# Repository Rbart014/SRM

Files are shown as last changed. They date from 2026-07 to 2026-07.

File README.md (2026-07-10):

# F-Class Solid Rocket Motor Static Characterization

**58.1 Ns | 25 mm OD | Single-Grain BATES | Designed in OpenMotor | Custom STM32 DAQ**

A fully documented amateur F-class solid rocket motor static fire test designed to build a complete engineering validation loop. This project includes 1D computational internal ballistics modeling, custom test stand fabrication, embedded C data acquisition development, and empirical thrust curve analysis for simulation calibration.

---

## Overview

| Parameter | Value |
|---|---|
| Motor Class | F (F78) |
| Total Impulse | 58.14 Ns (Actual) / 58.88 Ns (Predicted) |
| Peak Thrust | 93.07 N (Actual) / 134.67 N (Predicted) |
| Burn Time | ~1.40 s (Actual) / 0.72 s (Predicted) |
| Chamber Pressure | 8.24 MPa (Predicted) |
| Propellant Grain | Single-grain BATES (20.8 mm OD) |
| Propellant Length | 100 mm |
| Casing OD | 25 mm |
| Nozzle Throat Diameter | 3.89 mm |
| Nozzle Throat Length | 2.00 mm |
| Nozzle Exit Diameter | 8.20 mm |
| Expansion Ratio | 4.46 |
| DAQ Hardware | STM32 Microcontroller + HX711 |
| Test Stand Frame | 2040 Aluminum Extrusion |

---

## Repository Structure

```text
f-class-static-test/
├── simulation/           # OpenMotor 1D ballistics project files
├── DAQ/             # Custom C drivers for STM32 and HX711
├── test_data/            # Raw load cell CSVs from static firings
├── Cad/             # CAD files for custom metal motor mounts
├── images/               # Videos of firing, Post inspection
└── README.md

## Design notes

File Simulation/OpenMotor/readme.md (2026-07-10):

# OpenMotor 1D Internal Ballistics Simulation

This directory contains the computational simulation files used to predict the internal ballistics and thrust curve of the F-Class (F75) solid rocket motor prior to static testing. 

The primary tool used was **OpenMotor**, an open-source 1D internal ballistics solver for experimental solid rocket motors.

## Simulation Input Parameters

The initial predictive model was built using the following theoretical and geometric parameters:

| Component | Parameter | Value |
| :--- | :--- | :--- |
| **Propellant** | Type | KNSB (Potassium Nitrate / Sorbitol) |
| **Grain Geometry** | Configuration | Single-Grain BATES |
| | Outer Diameter (OD) | 0.819 in |
| | Length | 3.94 in |
| **Nozzle Geometry** | Throat Diameter | 0.153 in |
| | Throat Length | 0.079 in |
| | Exit Diameter | 0.323 in |
| | Expansion Ratio | 4.46 |
| | Convergence Half-Angle | 25° |
| | Divergence Half-Angle | 15° |
| **Assumptions** | C-Star Efficiency | 0.90 (Conservative sub-scale estimate) |

## Predicted vs. Empirical Calibration

The files currently in this directory represent the **pre-test predictive model**. 

Upon physical static testing, a significant deviation in the burn rate was observed. The OpenMotor simulation predicted a highly progressive burn over **0.72 seconds** with a peak chamber pressure of **1233 psi**. 

Empirical testing yielded a much longer, regressive burn over **~1.40 seconds**. Post-fire hardware inspection confirmed **0.000 in of nozzle throat erosion**, isolating the predictive failure entirely to the propellant characterization within the software.

## Files in this Directory
* `F78_Predictive_Model.eng` - The simulated thrust curve data exported from OpenMotor.
* `motor_sim.omtr` - The OpenMotor project save file.
* `SRM.png`

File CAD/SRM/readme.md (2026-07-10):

# Solid Rocket Motor (SRM) & Propellant Mold

> Mechanical design files, manufacturing tooling, and engineering drawings for an F-class Solid Rocket Motor.

## Overview
This directory contains the core 3D CAD assemblies and formal 2D drafts for the solid rocket motor. It encompasses the structural motor casing, the nozzle geometry, and the custom 3D-printed tooling required to cast the solid propellant grains.

## Core Models

### 1. SRM Hardware Assembly
The primary rocket motor structure, modeled around a **25 mm casing diameter**. The assembly details the integration of the motor casing, forward/aft closures, the converging-diverging nozzle, and the internal sacrificial thermal liners.

### 2. Propellant Casting Mold
Custom tooling designed for casting the solid propellant into a **single-grain Bates configuration**. The mold is desgined to be placed into the rocket casing as a type of experimental thermal liner made of polycarbonate.

### 3. Engineering Drawings
Formal 2D manufacturing drafts (`.pdf`). These drawings detail the critical dimensions, tolerances, and GD&T required to machine the motor hardware and verify the 3D-printed mold tolerances.

## Tools
* **Native CAD:** SolidWorks

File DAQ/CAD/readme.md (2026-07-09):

# Hardware Architecture: Static Test Stand

> Structural design and material specifications for the solid rocket motor static testing platform.

## Overview
The static test stand is engineered to safely secure the rocket motor during ignition and transfer the generated thrust linearly into the load cell for data acquisition. The physical structure balances modularity, rapid prototyping, and thermal resilience.

## Structural Components
* **Frame:** The core skeleton is constructed from **2040 aluminum extrusion**. This provides a rigid, modular backbone that resists bending moments during high-impulse static fires while allowing for easy adjustments to sensor placement.
* **Base & Mounts:** The primary base components and non-critical mounting brackets are 3D printed in **PETG**, chosen for its impact resistance and durability compared to standard PLA.
* **Motor Retention System:** The actual brackets holding the rocket motor are made of petg. They were able to withstand the heat as they never directly touched the rocket, only the screws that were holding the font closure and nozzle in place.

## Sensor Integration
The frame is specifically dimensioned to house the HX711 load cell assembly in direct axial alignment with the motor thrust vector, minimizing off-axis sheer forces and ensuring clean data transmission to the STM32 DAQ system.

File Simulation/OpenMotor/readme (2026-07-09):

# OpenMotor 1D Internal Ballistics Simulation

This directory contains the computational simulation files used to predict the internal ballistics and thrust curve of the F-Class (F75) solid rocket motor prior to static testing. 

The primary tool used was **OpenMotor**, an open-source 1D internal ballistics solver for experimental solid rocket motors.

## Simulation Input Parameters

The initial predictive model was built using the following theoretical and geometric parameters:

| Component | Parameter | Value |
| :--- | :--- | :--- |
| **Propellant** | Type | KNSB (Potassium Nitrate / Sorbitol) |
| **Grain Geometry** | Configuration | Single-Grain BATES |
| | Outer Diameter (OD) | 0.827 in |
| | Length | 3.94 in |
| **Nozzle Geometry** | Throat Diameter | 0.153 in |
| | Throat Length | 0.079 in |
| | Exit Diameter | 0.323 in |
| | Expansion Ratio | 4.46 |
| | Convergence Half-Angle | 25° |
| | Divergence Half-Angle | 15° |
| **Assumptions** | C-Star Efficiency | 0.90 (Conservative sub-scale estimate) |

## Predicted vs. Empirical Calibration

The files currently in this directory represent the **pre-test predictive model**. 

Upon physical static testing, a significant deviation in the burn rate was observed. The OpenMotor simulation predicted a highly progressive burn over **0.69 seconds** with a peak chamber pressure of **1195 psi**. 

Empirical testing yielded a much longer, regressive burn over **~1.40 seconds**. Post-fire hardware inspection confirmed **0.000 in of nozzle throat erosion**, isolating the predictive failure entirely to the propellant characterization within the software.

### Next Steps for Simulation (Iteration 2)
To build a calibrated model for future motor iterations, the empirical constants in OpenMotor's propellant database must be adjusted based on the static fire data:
1. **Burn Rate Coefficient (a) and Pressure Exponent (n):** The theoretical values utilized in this initial simulation significantly overestimated the burn rate for this specific chemical batch and curing environment. These parameters will be calibrated downward to match the 1.40 s empirical burn time.
2. **Efficiency Tuning:** Once burn time is calibrated via the burn rate constants, the C-Star efficiency parameter will be adjusted to accurately reflect the empirical 58.14 Ns total impulse.

## Files in this Directory
* `F75_Predictive_Model.eng` - The simulated thrust curve data exported from OpenMotor.
* `motor_sim.omtr` - The OpenMotor project save file.

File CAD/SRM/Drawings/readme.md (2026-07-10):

# Engineering & Manufacturing Drawings

> Formal 2D technical drafts and manufacturing specifications for the solid rocket motor and static test stand hardware.

## Overview
This directory contains the production-ready engineering drawings for all custom hardware. These documents establish the precise dimensions, tolerances, and material specifications required to transition the digital CAD models into physical, test-ready components.

### Motor Hardware
Detailed drafts for machining the primary pressure vessel and structural closures.
* **Motor Casing:** Specifications for the 25 mm outer diameter structural tube, including O-ring groove tolerances, wall thickness limits, and closure threading.
* **Closures & Nozzle:** Converging-diverging nozzle geometry and internal profiles designed to withstand peak chamber pressures and thermal flow.

## Standards & Formatting
All documents are provided in `.pdf` format for universal viewing by machinists or reviewers without requiring specialized CAD software. Drawings utilize standard Geometric Dimensioning and Tolerancing (GD&T) practices to clearly communicate functional limits and inspection criteria.

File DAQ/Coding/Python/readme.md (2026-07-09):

# Rocket Motor Thrust Logger GUI

> PC-side data acquisition and visualization software for an F-class solid rocket motor static test stand.

## Overview
This Python application serves as the ground station interface for the custom STM32 hardware. It establishes a serial connection to the microcontroller, reads incoming thrust telemetry, logs it securely to a timestamped CSV, and automatically generates a thrust curve plot for immediate performance analysis post-burn.

## Features
* **Live Telemetry:** Real-time thrust display built with Tkinter, utilizing a dedicated background thread to prevent UI blocking during high-speed serial reads.
* **Automated Data Logging:** Captures live UART data streams (115200 baud) and safely writes to uniquely timestamped CSV files, preventing data loss between static test fires.
* **Auto-Graphing:** Automatically parses the saved CSV and generates a scaled Thrust Curve (Time vs. Newtons) using Matplotlib immediately upon test completion.

## Technical Stack
* **Language:** Python 3
* **Libraries:** `tkinter` (GUI), `pyserial` (Hardware Comm), `matplotlib` (Data Visualization), `threading`, `csv`
* **Hardware Integration:** Designed to interface directly with STM32 UART outputs processing HX711 load cell data.

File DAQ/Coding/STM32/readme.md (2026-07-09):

# Rocket Motor DAQ Firmware

> Custom STM32 firmware for data acquisition on an F-class solid rocket motor static test stand.

## Overview
This project interfaces an STM32 microcontroller with an HX711 load cell amplifier to capture high-fidelity thrust data during static fires. It converts raw 24-bit ADC counts into real-time thrust measurements (Newtons) for performance analysis.

## Features
* **Precision DAQ:** Custom bit-banging C driver for the HX711 24-bit ADC.
* **Live Calibration:** Implements automated taring and applies a calibrated scale factor (`10435.78`).
* **Serial Streaming:** Transmits formatted floating-point data over UART (115200 baud) for live PC logging.

## Hardware Stack
* STM32 Microcontroller
* HX711 Load Cell Amplifier
* 2040 Aluminum Extrusion Frame
* Custom Metal Motor Retainers

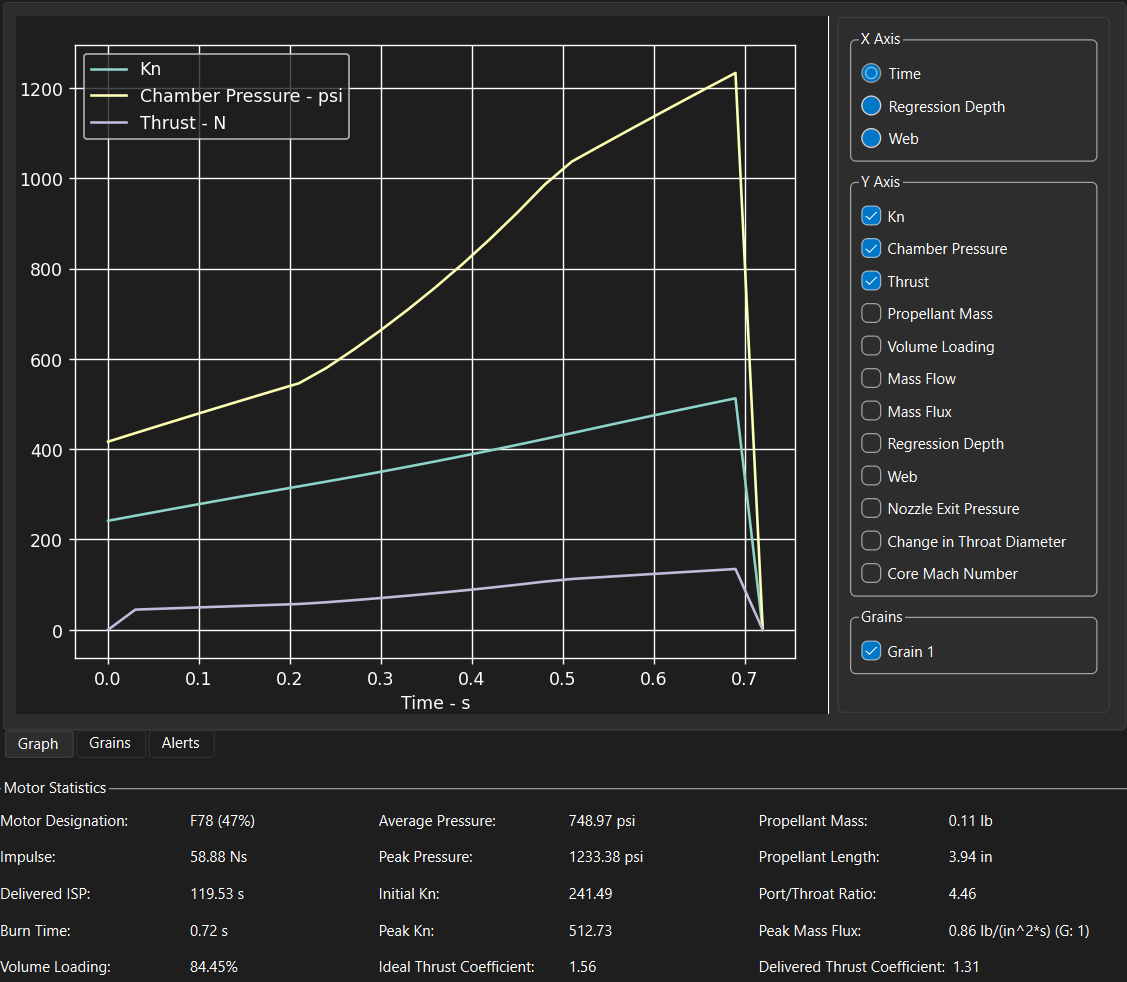
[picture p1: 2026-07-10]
Simulation/OpenMotor/SRM.png

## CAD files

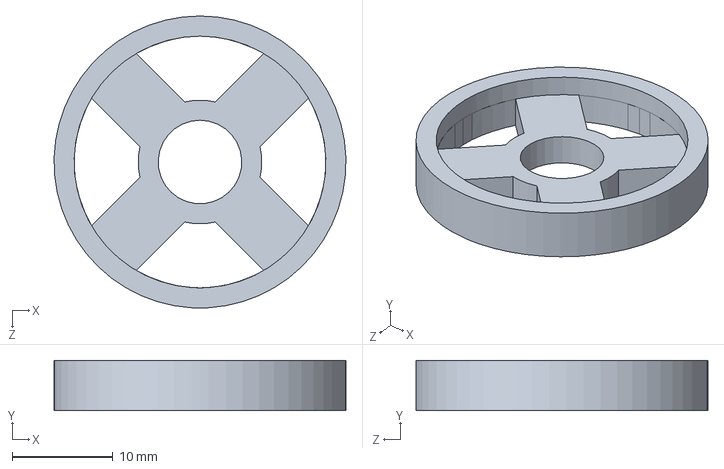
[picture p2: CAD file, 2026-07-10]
CAD/SRM/F-Class_Mold_Cap.SLDPRT
29.0 x 5.00 x 29.0 mm

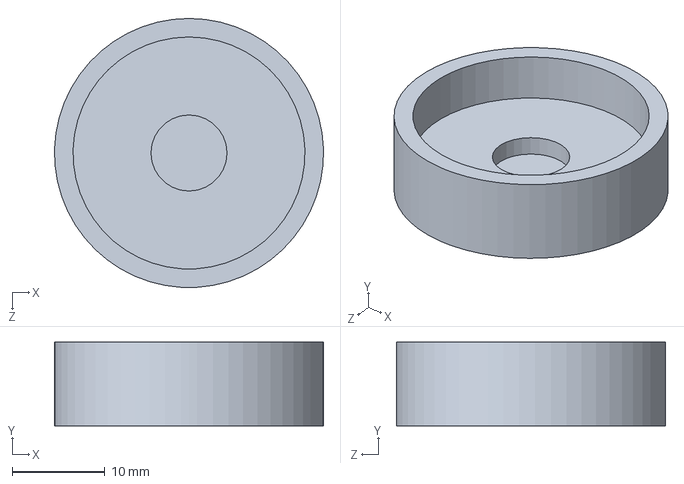
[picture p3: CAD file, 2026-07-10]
CAD/SRM/Mold_Bottom_Cap.SLDPRT
29.0 x 9.00 x 29.0 mm

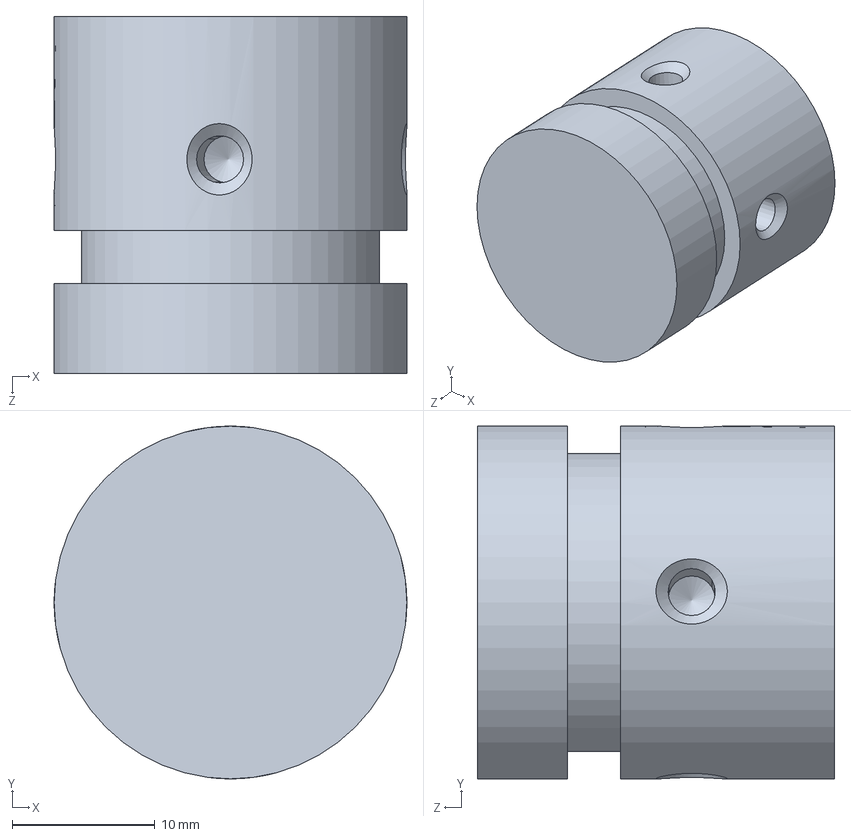
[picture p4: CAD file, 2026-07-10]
CAD/SRM/F-Class_Bulkhead.SLDPRT
24.7 x 24.7 x 25.0 mm

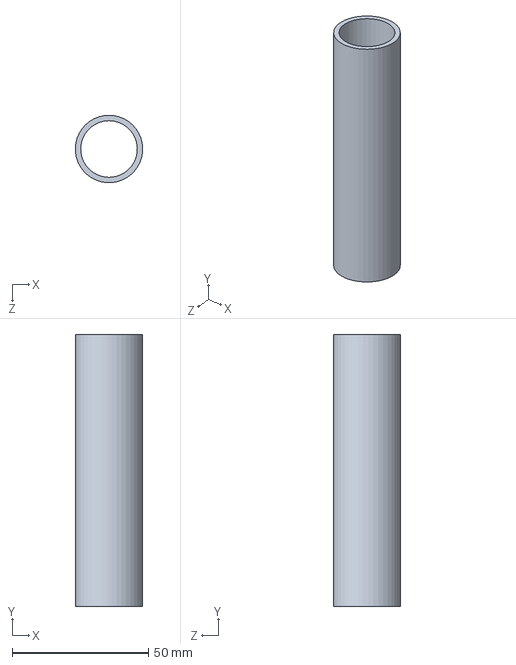
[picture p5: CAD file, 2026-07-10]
CAD/SRM/Thermal_Liner_Mold.SLDPRT
24.8 x 100.0 x 24.8 mm

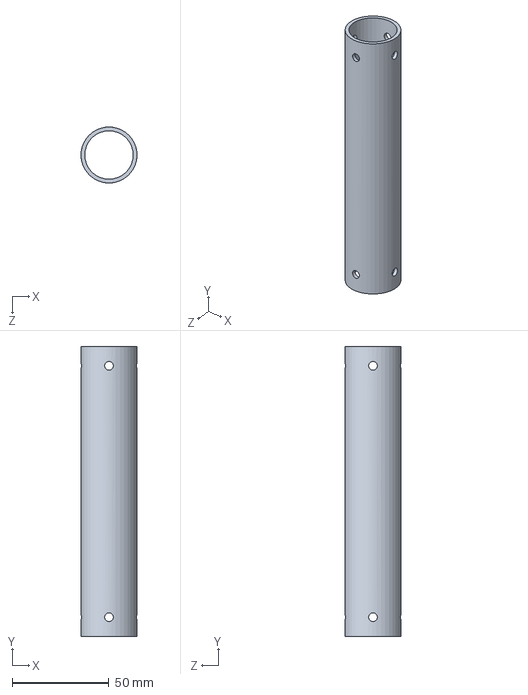
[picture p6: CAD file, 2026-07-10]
CAD/SRM/F-Class_Casing.SLDPRT
29.0 x 150.0 x 29.0 mm

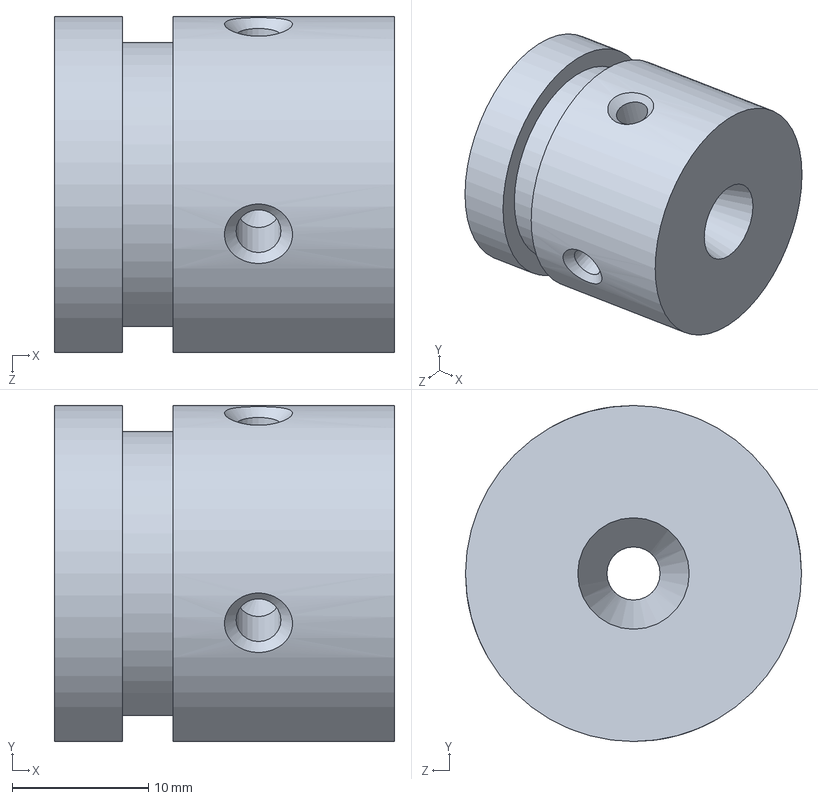
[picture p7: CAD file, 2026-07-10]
CAD/SRM/F-Class_Nozzle.SLDPRT
25.0 x 24.7 x 24.7 mm

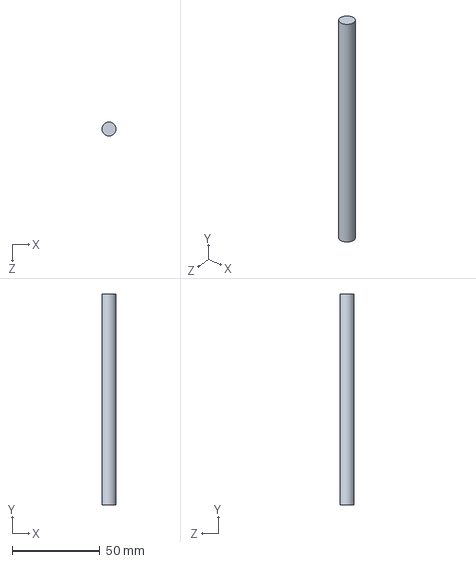
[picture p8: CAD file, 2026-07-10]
CAD/SRM/8MM_Mandrel.SLDPRT
7.99 x 120.0 x 8.00 mm

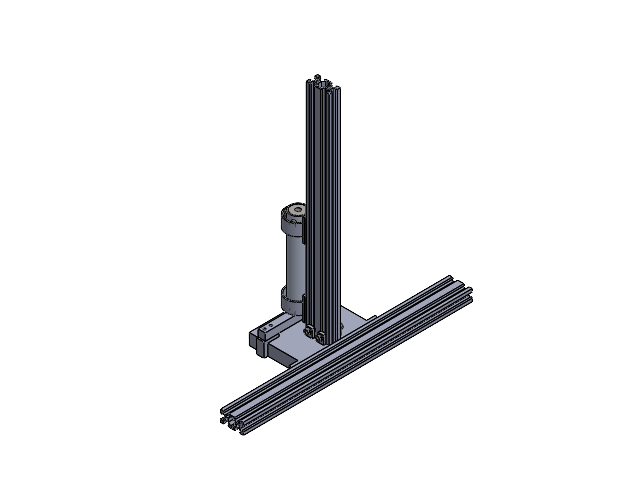
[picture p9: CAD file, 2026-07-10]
DAQ/CAD/Test_Stand.SLDASM
2040 400mm x 2
Test_Stand_Base_Plate
F-Class_Nozzle
F-Class_Bulkhead
F-Class_Casing
Thermal_Liner
91290A221_Black-Oxide Alloy Steel Socket Head Screw x 9
F-Class_Collar x 2
Load_Cell
91290A113_Black-Oxide Alloy Steel Socket Head Screw x 5
91290A224_Black-Oxide Alloy Steel Socket Head Screw x 4

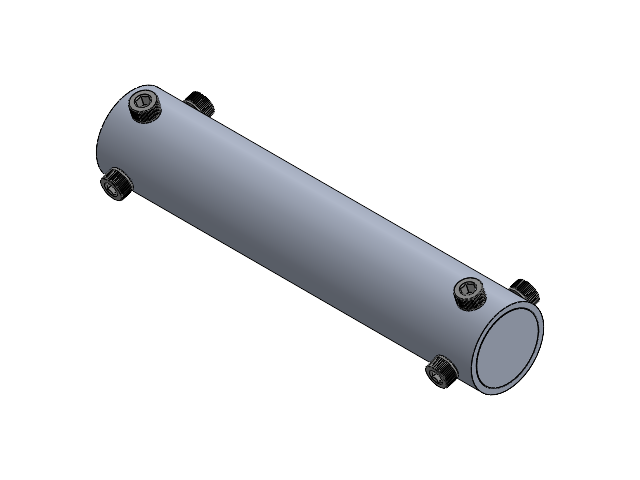
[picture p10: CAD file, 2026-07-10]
CAD/SRM/F-Class_Assembly.SLDASM
F-Class_Nozzle
F-Class_Bulkhead
F-Class_Casing
Thermal_Liner
91290A221_Black-Oxide Alloy Steel Socket Head Screw x 8

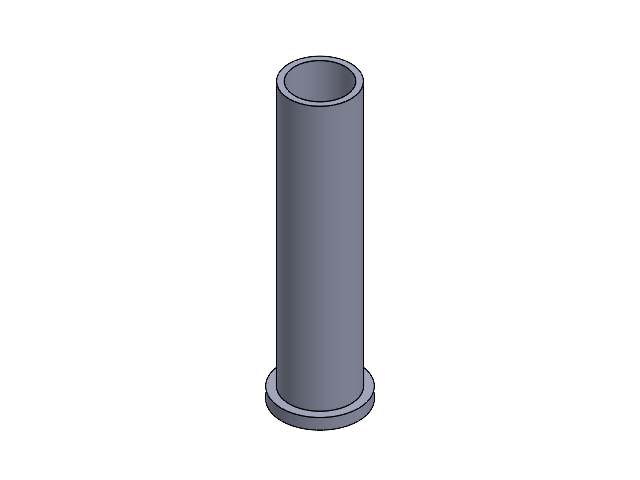
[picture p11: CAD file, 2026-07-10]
CAD/SRM/F-Class_Casting_Mold_Assembly.SLDASM
F-Class_Mold_Bottom
F-Class_Mold_Case

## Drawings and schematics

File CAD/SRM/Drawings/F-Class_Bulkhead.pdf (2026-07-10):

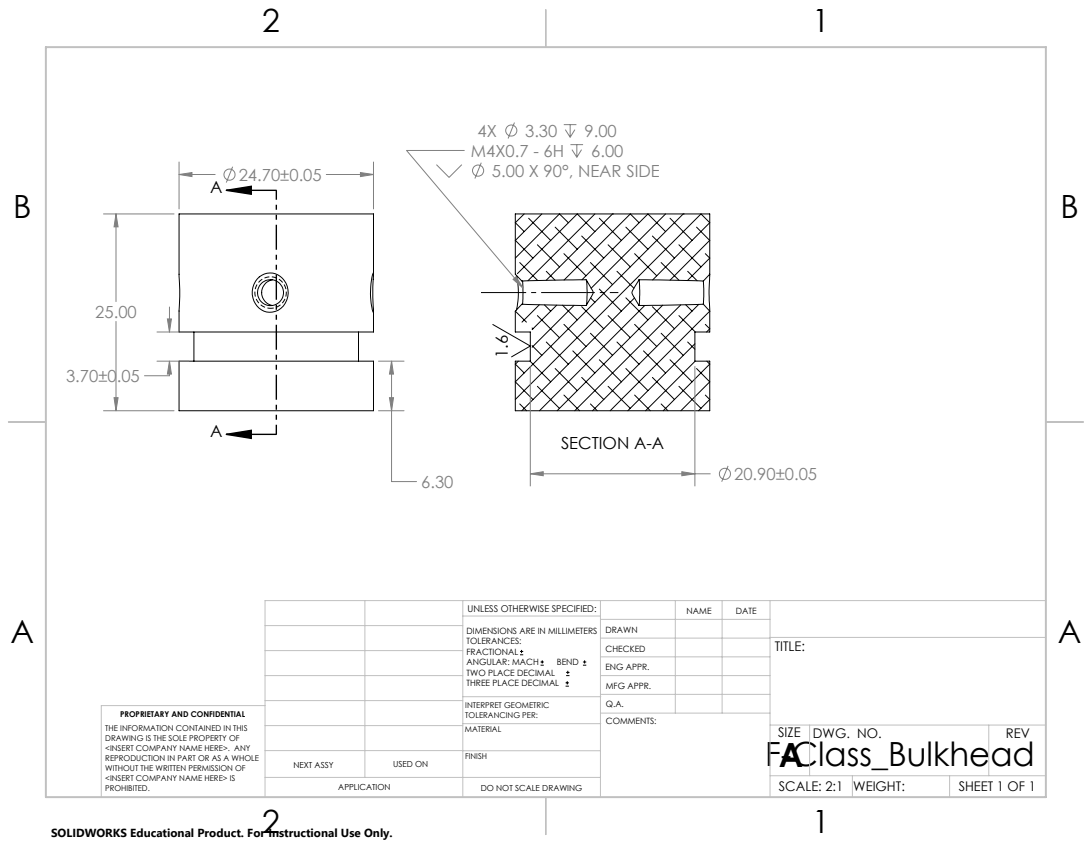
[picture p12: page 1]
M4X0.7 - 6H 6.00 5.00 X 90°, NEAR SIDE; SECTION A-A

UNLESS OTHERWISE SPECIFIED: | | NAME | DATE
DIMENSIONS ARE IN MILLIMETERS TOLERANCES: FRACTIONAL ANGULAR: MACH BEND TWO PLACE DECIMAL THREE PLACE DECIMAL | DRAWN

CHECKED | | | TITLE:

ENG APPR.
MFG APPR.

INTERPRET GEOMETRIC TOLERANCING PER: | Q.A.
MATERIAL | F-Class_Bulkhead | SIZE A | DWG. NO. | REV

PROPRIETARY AND CONFIDENTIAL
THE INFORMATION CONTAINED IN THIS
DRAWING IS THE SOLE PROPERTY OF
<INSERT COMPANY NAME HERE>. ANY
REPRODUCTION IN PART OR AS A WHOLE
WITHOUT THE WRITTEN PERMISSION OF
<INSERT COMPANY NAME HERE> IS
PROHIBITED.

NEXT ASSY | USED ON | FINISH

APPLICATION | DO NOT SCALE DRAWING | | SCALE: 2:1 | WEIGHT: | SHEET 1 OF 1

SOLIDWORKS Educational Product. For Instructional Use Only.

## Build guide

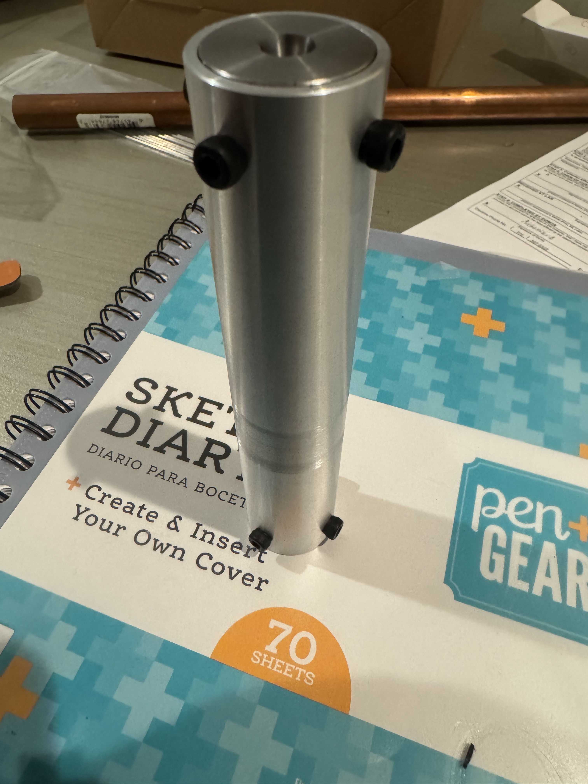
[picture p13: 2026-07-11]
Video and Images/Test 1/Full Assembly.jpg

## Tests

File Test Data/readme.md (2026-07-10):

## Static Fire Results
Below are the empirical thrust curves generated by the Python ground station during recent static test fires. The data tracking did start a few seconds before actual ignitiion. 

**Test Iteration 1:**
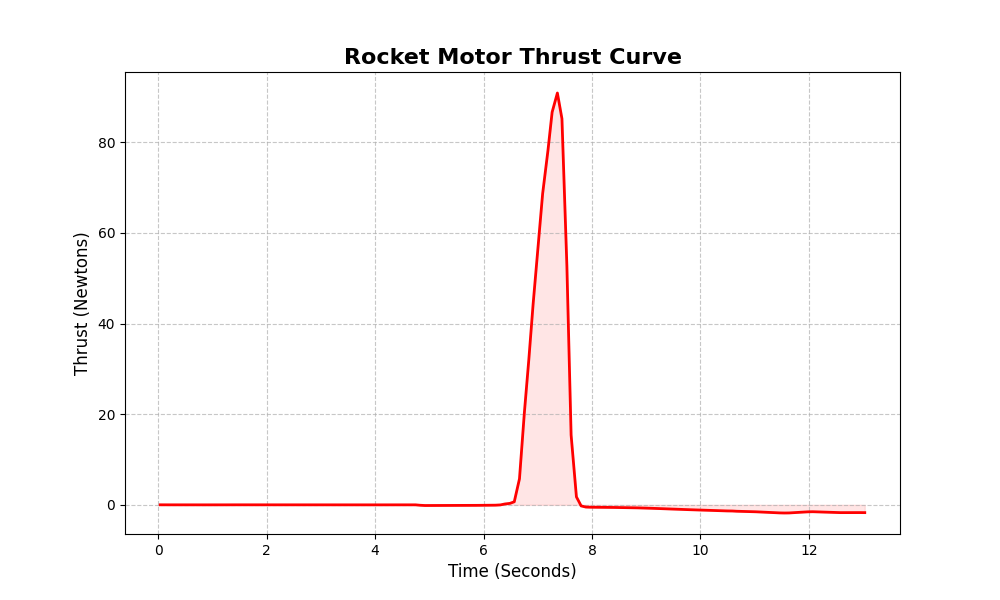
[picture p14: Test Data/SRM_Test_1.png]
Thrust Curve Test 1


**Test Iteration 2:**
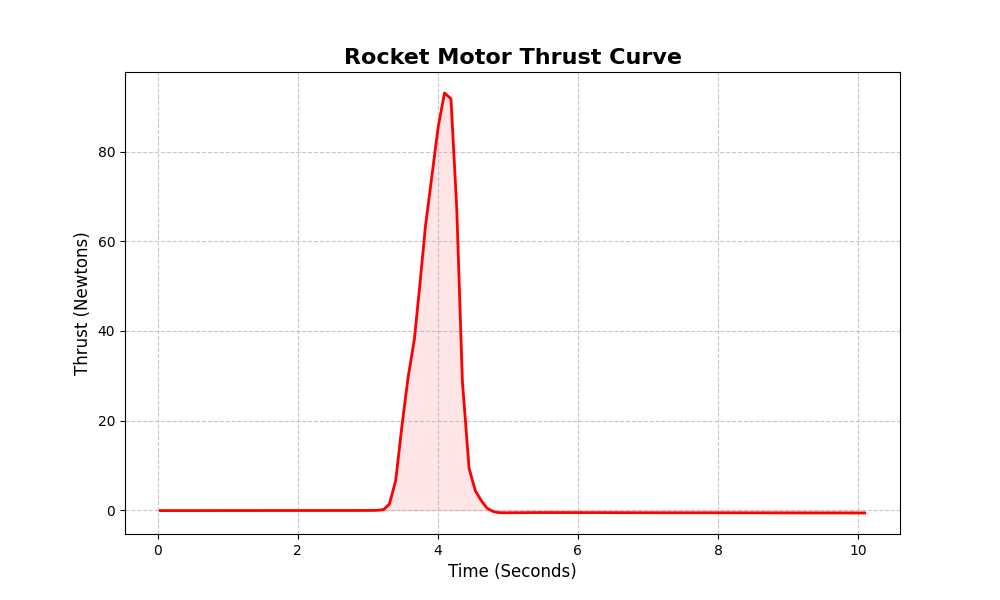
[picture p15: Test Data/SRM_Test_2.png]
Thrust Curve Test 2


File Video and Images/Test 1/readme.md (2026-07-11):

# Static Fire Test 01

This directory contains the documentation, media, and post-test breakdown for the first static fire test of the custom solid rocket motor.

## Motor Specifications
* **Propellant:** KNSB (Meltcast)
* **Configuration:** Single-grain Bates (20.8 mm OD)
* **Casing:** 25 mm diameter
* **Thermal Management:** 3D Printed Polycarbonate (PC) liner

## Test 01 Media & Documentation
The following files document the pre-test assembly and post-test structural and thermal evaluation:

* **Pre-Test Files:** 
  * `Full Assembly.jpg`
  * `KNSB meltcast.jpg` 
  * `Igniter.jpg`
  * `PC mold_liner.jpg`
* **Post-Test Breakdown:** 
  * `Assembly after test.jpg`
  * `Casing after test.jpg`
  * `Front Closure and Nozzle after test.jpg`

## Static Fire Footage
* `Test 1 video.mp4`

## Test Objectives
The primary goal of Test 01 was to establish a baseline for the motor's internal ballistics and to validate the survivability of the 3D-printed PC thermal liner under live pressure and thermal soak-back conditions.

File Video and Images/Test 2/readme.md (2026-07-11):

# Static Fire Test 02

This directory contains the post-test documentation and media for the second static fire test of the custom solid rocket motor. 

## Motor Specifications
* **Propellant:** KNSB (Meltcast)
* **Configuration:** Single-grain Bates (20.8 mm OD)
* **Casing:** 25 mm diameter
* **Thermal Management:** 3D Printed Polycarbonate (PC) liner

## Test 02 Media & Documentation
This iteration specifically focuses on post-test component degradation. The following files document the structural and thermal evaluation after firing:

* **Post-Test Breakdown:** 
  * `Casing post fire.jpg`
  * `Nozzle and Front Closure post fire.jpg`
  * `Nozzle post fire.jpg`
  * `PC liner post fire.jpg`

* **Static Fire Footage:** 
  * `Test 2 video.mp4` (Includes the complete video recording of the live static fire on the test stand).

## Test Objectives & Observations
Building upon the baseline established in Test 01, this firing continued to evaluate internal ballistics and the structural safety of the motor components. The post-fire media specifically highlights the survivability of the 3D-printed PC thermal liner and assesses thermal soak-back wear on the aluminum casing, closures, and nozzle.

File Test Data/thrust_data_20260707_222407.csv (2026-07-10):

Time (s) | Thrust (N)
0.036 | -0.060
0.041 | -0.061
0.044 | -0.060
0.047 | -0.062
0.047 | -0.062
0.047 | -0.065
0.047 | -0.063
0.052 | -0.062
0.052 | -0.063
0.052 | -0.063
0.052 | -0.061
0.052 | -0.063
0.085 | -0.062
0.181 | -0.061
0.266 | -0.063
0.357 | -0.064
0.439 | -0.066
0.532 | -0.061
0.615 | -0.066
0.707 | -0.065
0.784 | -0.058
0.879 | -0.060
0.961 | -0.062
1.055 | -0.061
1.135 | -0.057
1.229 | -0.062
1.315 | -0.063
1.387 | -0.063
1.483 | -0.064
1.563 | -0.064
1.659 | -0.064
1.738 | -0.067
1.835 | -0.062
1.924 | -0.055
2.008 | -0.064
2.091 | -0.062
2.184 | -0.057
2.265 | -0.055
2.359 | -0.055
2.439 | -0.055
2.533 | -0.053
2.620 | -0.052
2.693 | -0.053
2.788 | -0.047
2.870 | -0.041
2.966 | -0.039
3.055 | -0.031
3.135 | -0.001
3.225 | 0.160
3.309 | 1.422
3.398 | 6.618
3.486 | 18.656
3.573 | 29.390
3.665 | 38.188
3.744 | 50.448
3.824 | 63.506
3.919 | 75.093
4.006 | 85.638
4.095 | 93.074
4.187 | 91.798
4.270 | 67.390
4.350 | 28.886
4.446 | 9.338
4.535 | 4.360
4.620 | 2.169
4.700 | 0.507
4.795 | -0.308
4.868 | -0.518
4.963 | -0.555
5.055 | -0.542
5.134 | -0.523
5.229 | -0.517
5.308 | -0.513
5.403 | -0.508
5.489 | -0.516
5.570 | -0.511
5.651 | -0.508
5.750 | -0.507
5.840 | -0.510
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

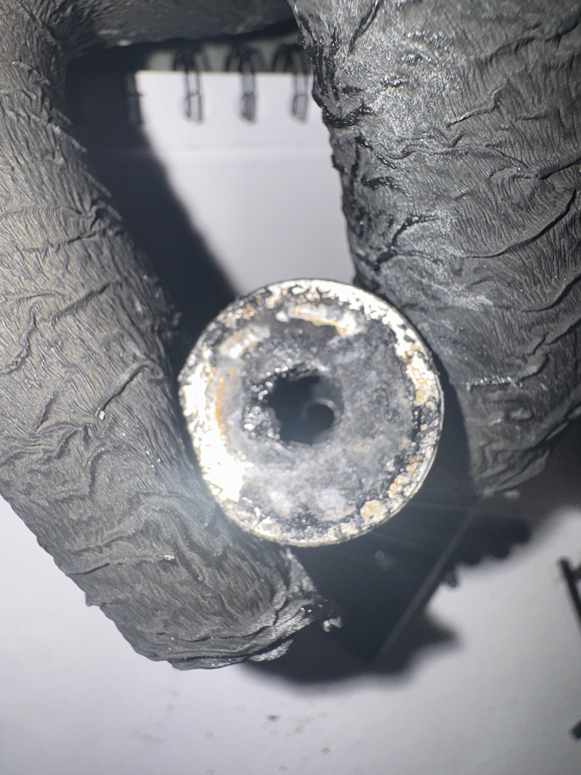
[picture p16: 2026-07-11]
Video and Images/Test 2/Nozzle post fire.jpg

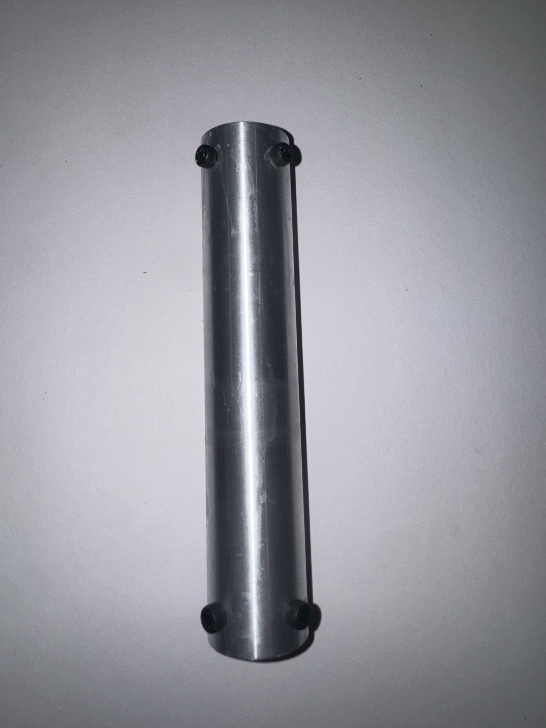
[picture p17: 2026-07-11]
Video and Images/Test 1/Assembly after test.jpg

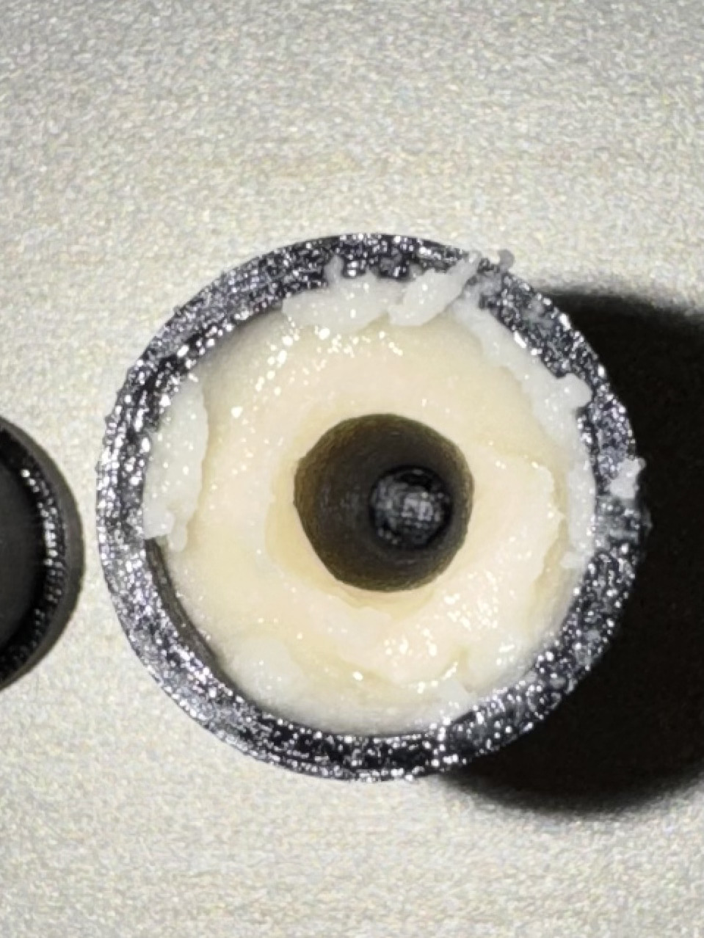
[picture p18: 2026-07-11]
Video and Images/Test 1/KNSB meltcast.jpg

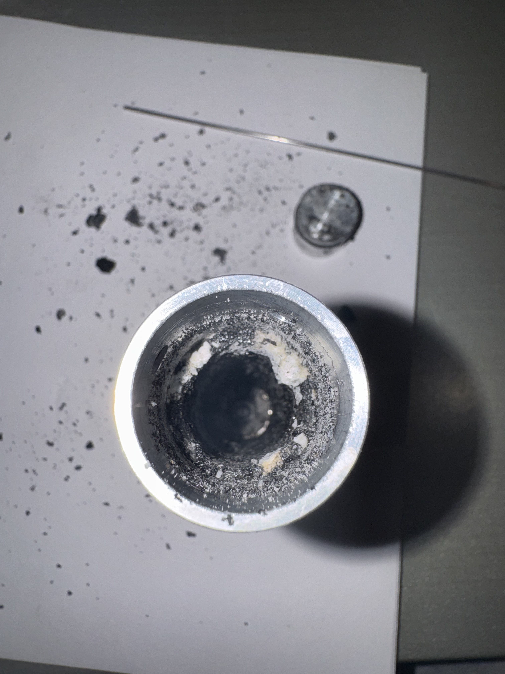
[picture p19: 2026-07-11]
Video and Images/Test 1/Casing after test.jpg

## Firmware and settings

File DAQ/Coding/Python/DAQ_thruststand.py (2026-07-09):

import tkinter as tk
from tkinter import messagebox
import serial
import time
import csv
import threading
import matplotlib.pyplot as plt

class ThrustLoggerGUI:
    def __init__(self, root):
        self.root = root
        self.root.title("🚀 Rocket Thrust Logger")
        self.root.geometry("400x350")
        self.root.configure(bg="#f0f0f0")
        
        self.is_recording = False
        self.serial_port = None
        self.data_thread = None
        self.start_time = 0
        self.csv_file = None
        self.csv_writer = None
        
        # --- NEW: Variable to hold our unique filename for each run ---
        self.current_filename = "" 
        
        # --- UI Elements ---
        tk.Label(root, text="COM Port:", font=("Arial", 12), bg="#f0f0f0").pack(pady=(20, 5))
        
        self.port_entry = tk.Entry(root, font=("Arial", 12), justify="center")
        self.port_entry.insert(0, "COM7") # Updated default to your working COM7!
        self.port_entry.pack(pady=5)
        
        self.thrust_label = tk.Label(root, text="0.000 N", font=("Courier", 40, "bold"), fg="#0052cc", bg="#f0f0f0")
        self.thrust_label.pack(pady=20)
        
        self.status_label = tk.Label(root, text="Status: Ready", font=("Arial", 10, "italic"), fg="gray", bg="#f0f0f0")
        self.status_label.pack(pady=5)
        
        # --- Buttons ---
        self.start_btn = tk.Button(root, text="🟢 Start Recording", font=("Arial", 14, "bold"), bg="#a8e6cf", command=self.start_recording)
        self.start_btn.pack(pady=5, fill="x", padx=60)
        
        self.stop_btn = tk.Button(root, text="🛑 Stop, Save & Graph", font=("Arial", 14, "bold"), bg="#ff8b94", state=tk.DISABLED, command=self.stop_recording)
        self.stop_btn.pack(pady=5, fill="x", padx=60)
        
    def start_recording(self):
        port = self.port_entry.get()
        
        try:
            self.serial_port = serial.Serial(port, 115200, timeout=1)
            time.sleep(1) 
        except Exception as e:
            messagebox.showerror("Connection Error", f"Could not open {port}.\n\nError: {e}")
            return
            
        # --- NEW: Create a unique file based on the exact date and time ---
        timestamp = time.strftime("%Y%m%d_%H%M%S")
        self.current_filename = f"thrust_data_{timestamp}.csv"
        
        self.csv_file = open(self.current_filename, "w", newline="")
        self.csv_writer = csv.writer(self.csv_file)
        self.csv_writer.writerow(["Time (s)", "Thrust (N)"])
        
        self.is_recording = True
        self.start_time = time.time()
        
        self.start_btn.config(state=tk.DISABLED)
        self.stop_btn.config(state=tk.NORMAL)
        self.port_entry.config(state=tk.DISABLED)
        self.status_label.config(text="Status: 🔴 RECORDING...", fg="red")
        
        self.data_thread = threading.Thread(target=self.read_serial_data, daemon=True)
        self.data_thread.start()
        
    def read_serial_data(self):
        while self.is_recording and self.serial_port.is_open:
            try:
                if self.serial_port.in_waiting > 0:
                    line = self.serial_port.readline().decode('utf-8', errors='ignore').strip()
                    if line:
                        try:
                            thrust = float(line)
                            current_time = time.time() - self.start_time
                            
                            self.csv_writer.writerow([f"{current_time:.3f}", f"{thrust:.3f}"])
                            self.root.after(0, self.update_thrust_label, f"{thrust:.3f} N")
                            
                        except ValueError:
                            pass
            except Exception as e:
                print(f"Lost connection: {e}")
                break

    def update_thrust_label(self, text):
        self.thrust_label.config(text=text)

    def stop_recording(self):
        if not self.is_recording:
            return
            
        self.is_recording = False
        
        if self.serial_port and self.serial_port.is_open:
            self.serial_port.close()
        if self.csv_file:
            self.csv_file.close()
            
        self.start_btn.config(state=tk.NORMAL)
        self.stop_btn.config(state=tk.DISABLED)
        self.port_entry.config(state=tk.NORMAL)
        
        # --- NEW: Update the label to show the exact file it just saved ---
        self.status_label.config(text=f"Status: 💾 Saved to {self.current_filename}", fg="green")
        
        self.plot_data()

    def plot_data(self):
        time_data = []
        thrust_data = []
        
        # --- NEW: Tell the graph to open the specific file we just created ---
        try:
            with open(self.current_filename, "r") as file:
                reader = csv.reader(file)
                next(reader) 
                for row in reader:
                    time_data.append(float(row[0]))
                    thrust_data.append(float(row[1]))
                    
            plt.figure(figsize=(10, 6))
            plt.plot(time_data, thrust_data, color='red', linewidth=2)
            plt.title("Rocket Motor Thrust Curve", fontsize=16, fontweight='bold')
            plt.xlabel("Time (Seconds)", fontsize=12)
            plt.ylabel("Thrust (Newtons)", fontsize=12)
            plt.grid(True, linestyle='--', alpha=0.7)
            plt.fill_between(time_data, thrust_data, color='red', alpha=0.1) 
            
            plt.show()
            
        except Exception as e:
            messagebox.showerror("Graphing Error", f"Could not generate graph.\n\nError: {e}")

def on_closing():
    if app.is_recording:
        app.stop_recording()
    root.destroy()

if __name__ == "__main__":
    root = tk.Tk()
    app = ThrustLoggerGUI(root)
    root.protocol("WM_DELETE_WINDOW", on_closing)
    root.mainloop()

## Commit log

2026-04-11 Revise README for G-Class KNSB Solid Rocket Motor
    Updated the README to reflect the G-Class KNSB Solid Rocket Motor details, including specifications, design process, project status, tools, and author information.
2026-07-09 Create STM32
2026-07-09 Update readme with hardware architecture details
    Added detailed hardware architecture and specifications for the static test stand, including structural components and sensor integration.
2026-07-10 Update readme with tracking start time clarification
    Clarified the description of the thrust curves by mentioning the data tracking start time.
2026-07-10 Update readme with SRM project details
    Added detailed information about the Solid Rocket Motor project, including core models and tools used.
2026-07-10 Update motor class from F75 to F78
2026-07-11 Add readme for solid rocket motor static test
    Added detailed documentation for the solid rocket motor static test, including specifications, media, and analysis.
2026-07-11 Correct motor configuration diameter in readme
